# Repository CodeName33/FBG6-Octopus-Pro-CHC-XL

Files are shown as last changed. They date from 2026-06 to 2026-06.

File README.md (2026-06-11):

# FlyingBear Ghost 6 modifications for Octopus-Pro and CHC-XL
## What to buy
 * Octopus Pro H723
 * TMC2240 x5
 * "Nail" Fan 40x15 24v x2
 * "Nail" Fan 40x20 24v
 * Order custom bed heater using [drawings/heater.png](drawings/heater.png) (220v 500w) (may be here, write message to seller https://aliexpress.ru/store/911266084)
 * SSR-40-DA Relay
 * CHC-XL
 * 5Aplusreprap for PRUSAI3 MK8 (https://aliexpress.ru/item/1005003334340394.html) [images/feeder.jpg](images/feeder.jpg)
 * Nema 14 36mm (36STH20-1004HG)
 * 300x300x3 acrylic glass
 * 3D Touch [images/3dtouch.jpg](images/3dtouch.jpg)
 * 120mm FAN (PC FAN)
 * LEDS (or use Built in)
 * Any Pi computer (Oprange Pi, Raspberry Pi, etc. I use Orange Pi Zero 3)

## Connection
 * X - MOTOR0
 * Y - MOTOR1
 * Z - MOTOR3
 * Extruder - MOTOR4
 * Bed Heater (220v through Relay SSR-40-DA) - HE0
 * Bead Heater Temperature Sensor - TB
 * Hotend Heater - HE1
 * Hotend Temperature Sensor - T0
 * Hotend Fan ("Nail" Fan 40x20 24v) - FAN0 (Switch VFAN to 24v)
 * Model cool fan ("Nail" Fan 40x15 24v x2) - FAN1 (Switch VFAN to 24v)
 * Chamber fan (Built in) - FAN2 (Switch VFAN to 24v)
 * LED light - FAN3 (Switch VFAN to LEDs voltage, built in LEDs are 5v)
 * Electronics fan (120mm FAN) - FAN2 (Switch VFAN to 12v)
 * 3D Touch - PROBE
 * Pi to Octopus - (RX-TX, TX-RX, 5V-5V, GND-GND)
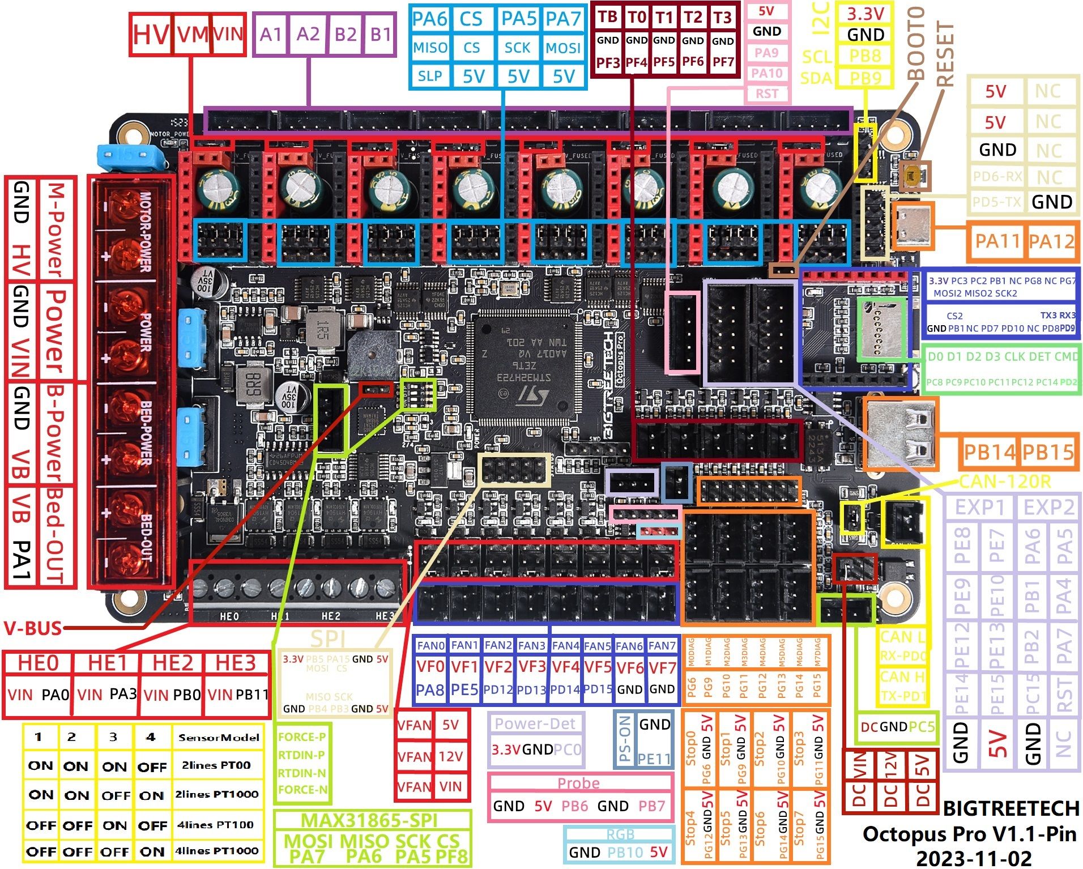
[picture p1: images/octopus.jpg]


## Folders
 * **images** - Just images
 * **drawings** - Drawings for some parts
 * **configs** - Klipper configs
 * **models** - 3d models for print (**stable** - stable models)

## Print
 1. Print "**Head VXX.stl**" from models/stable (Split it in slicer, yeah it's will be hard to print Head V1.0 bottom part). (Feeder made by Dmitry Sorkin from project Vostok)
 2. Screen not used, so panel named **screen-place.stl** can be used

(will be updated soon...)

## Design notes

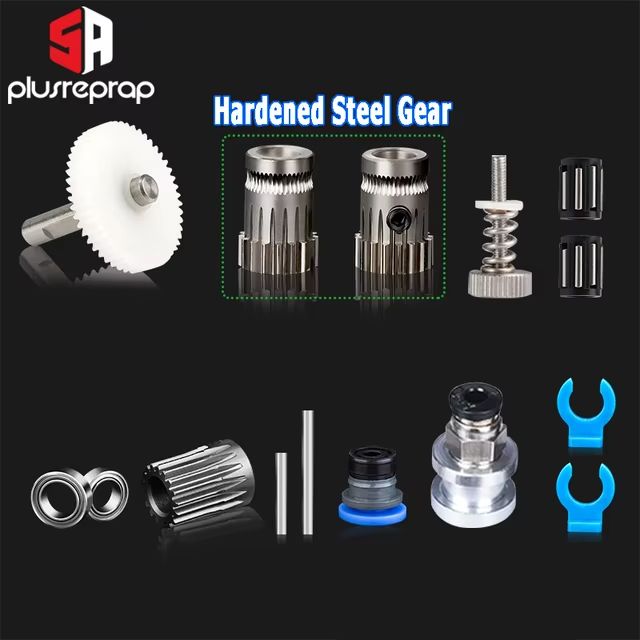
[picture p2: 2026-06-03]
images/feeder.jpg

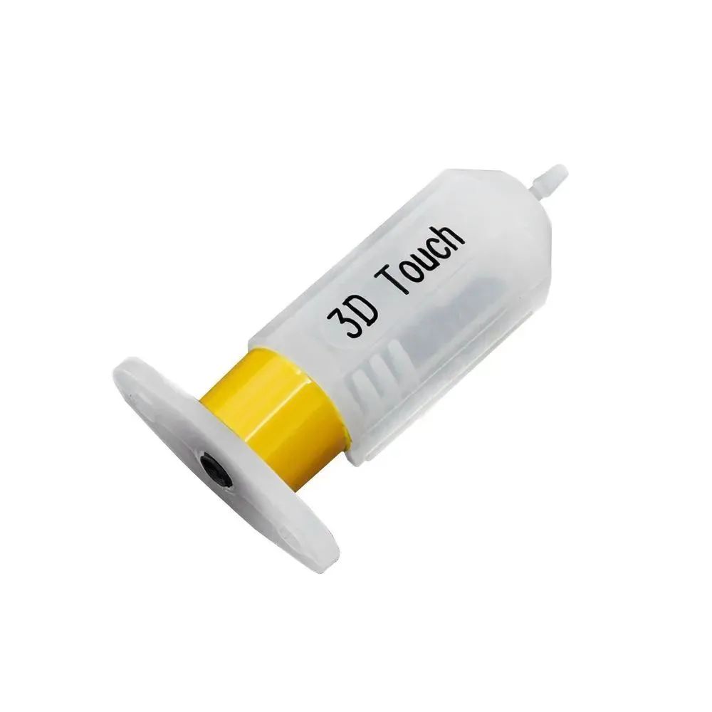
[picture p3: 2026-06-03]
images/3dtouch.jpg

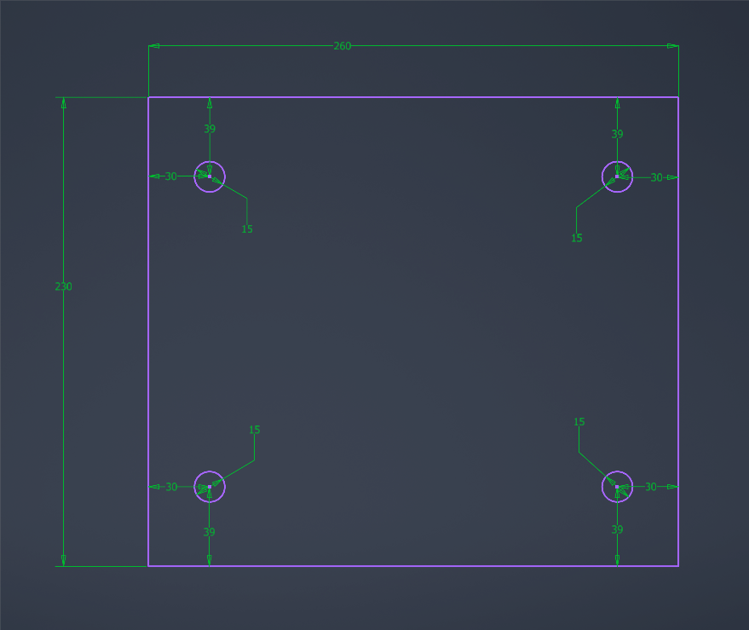
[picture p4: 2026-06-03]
drawings/heater.png

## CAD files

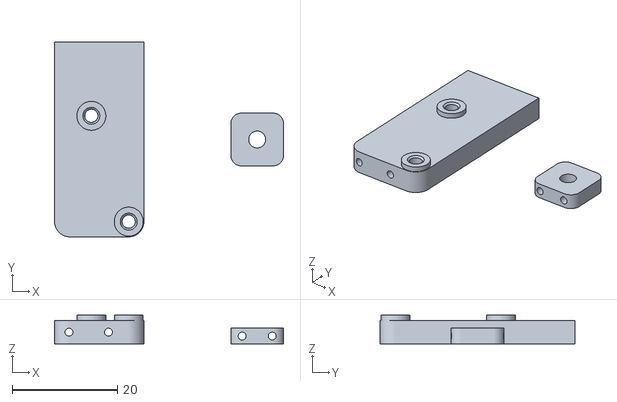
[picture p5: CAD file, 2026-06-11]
models/stable/cam-holder.stl
43.5 x 37.0 x 5.50

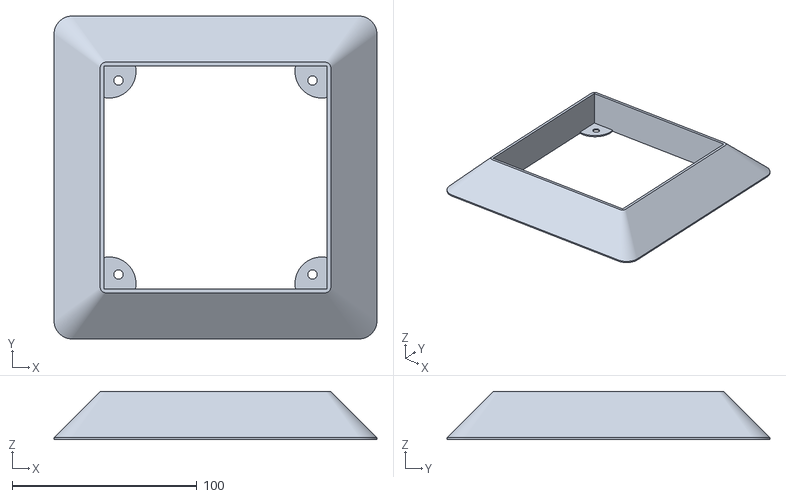
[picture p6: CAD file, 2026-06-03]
models/stable/vent-out.stl
174.8 x 174.8 x 26.0

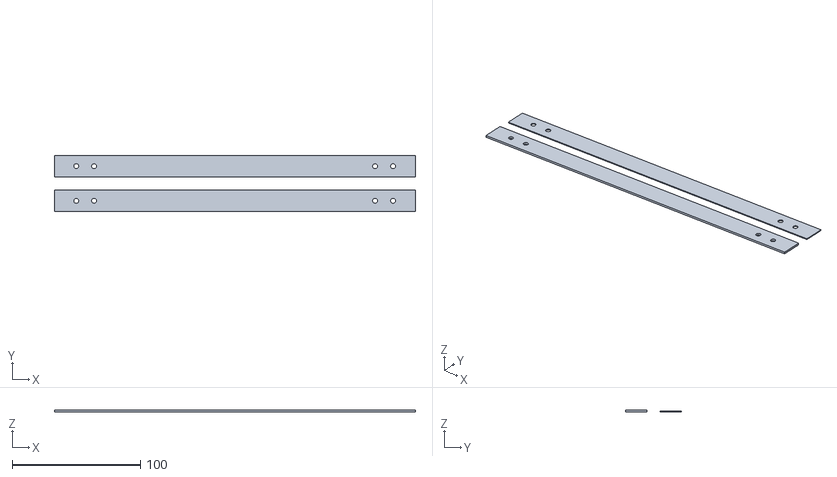
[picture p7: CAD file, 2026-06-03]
models/stable/door-fix.stl
282.0 x 44.0 x 1.50

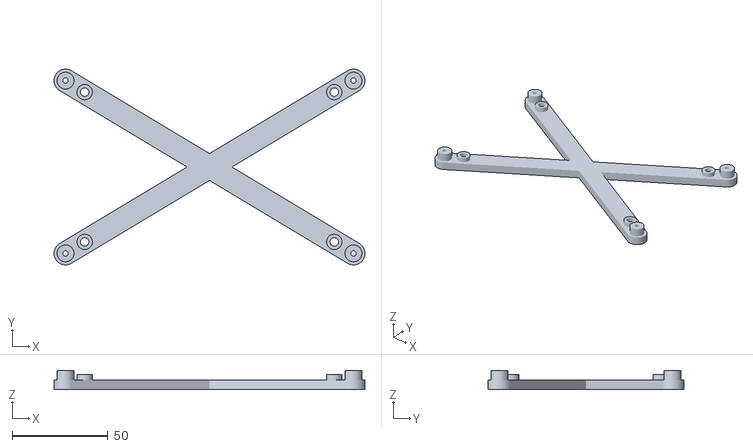
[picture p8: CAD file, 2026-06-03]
models/stable/octopus-holder.stl
162.0 x 102.0 x 10.0

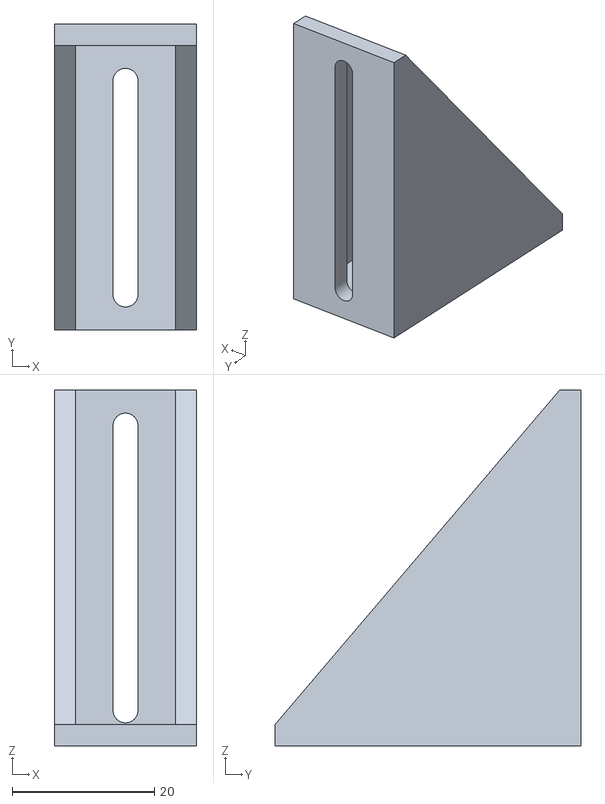
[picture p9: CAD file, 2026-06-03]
models/stable/bottom-holder.stl
20.0 x 43.0 x 50.0

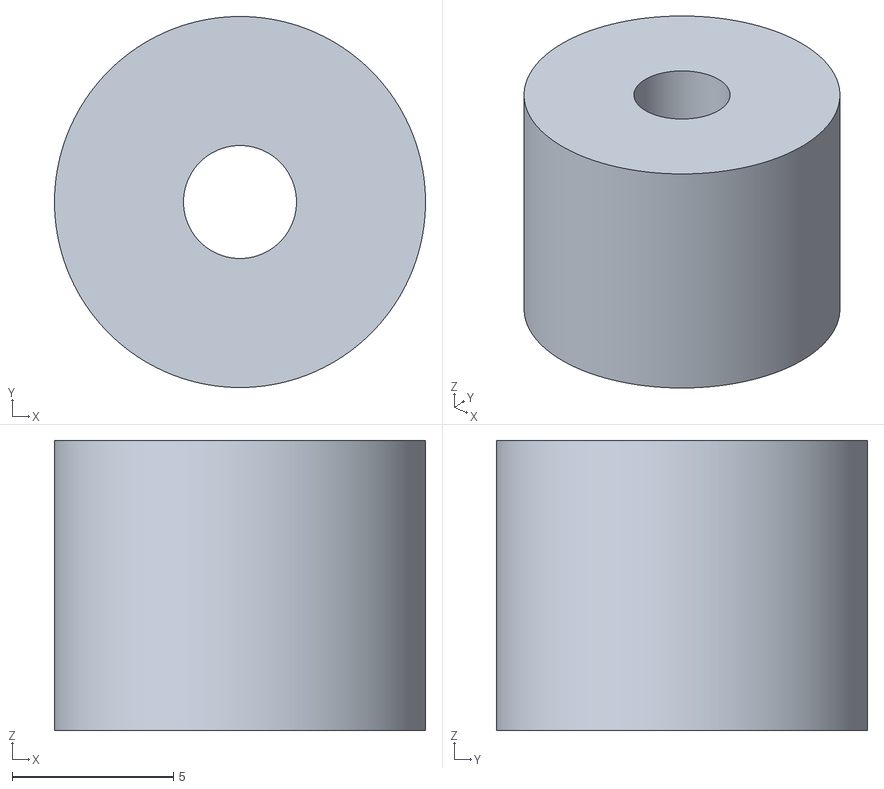
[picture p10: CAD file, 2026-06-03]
models/stable/side-holder.stl
11.5 x 11.5 x 9.00

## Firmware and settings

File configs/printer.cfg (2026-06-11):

[include printer_hardware.cfg]
[include printer_base.cfg]



[mcu]
serial: /dev/ttyS5
baud: 250000
restart_method: command 

[virtual_sdcard]
path: /home/user/printer_data/gcodes
on_error_gcode: CANCEL_PRINT

[printer]
kinematics: corexy
max_velocity: 500
max_accel: 20000
minimum_cruise_ratio: 0.5
square_corner_velocity: 10
max_z_velocity: 20
max_z_accel: 100

[stepper_x]
position_min: 0
position_endstop: 0
position_max: 255

[stepper_y]
position_min: 0
position_endstop: 0
position_max: 210

[stepper_z]
position_max: 200

[extruder]
max_temp: 320
rotation_distance: 4.5
sensor_type: PT1000
full_steps_per_rotation: 200

[heater_bed]
sensor_type: EPCOS 100K B57560G104F

[safe_z_home]
home_xy_position: 149, 132 # Центр вашего стола
speed: 400
z_hop: 6                  # Поднять сопло перед движением
z_hop_speed: 20

[bed_mesh]
mesh_min: 4.0,0.0 # Левая передняя точка, в которой будет снята карта высот стола. Указывается координата именно точки, в которой снимается высота. Положение головы при этом будет смещено на значения -x_offset и -y_offset
mesh_max: 233.0,183.0 # Правая задняя точка, в которой будет снята карта высот стола. Указывается координата именно точки, в которой снимается высота. Положение головы при этом будет смещено на значения -x_offset и -y_offset
probe_count: 9,7 # Количество точек карты высот стола вдоль осей X, Y
zero_reference_position: 127.0,105.0 # Координаты центра стола


[input_shaper]
#shaper_type_x: 3hump_ei
#shaper_freq_x: 53.38
#shaper_type_y: 3hump_ei
#shaper_freq_y: 53.38

shaper_type_x: 2hump_ei
shaper_freq_x: 54.02
shaper_type_y: 2hump_ei
shaper_freq_y: 62.02

#damping_ratio_x: 0.1
#damping_ratio_y: 0.145
#shaper_type_x: mzv
#shaper_freq_x: 30.03
#shaper_type_y: mzv
#shaper_freq_y: 33.55
#shaper_type_x: mzv
#shaper_freq_x: 60.8
#shaper_type_y: mzv
#shaper_freq_y: 57.4


#[mcu btt_s2dw]
#serial: /dev/serial/by-id/usb-Klipper_rp2040_50445061303ED21C-if00 # Замените на ваш ID

#[lis2dw]
#cs_pin: btt_s2dw:gpio9
#spi_software_sclk_pin: btt_s2dw:gpio10
#spi_software_mosi_pin: btt_s2dw:gpio11
#spi_software_miso_pin: btt_s2dw:gpio8
#axes_map: x, y, z 

#[resonance_tester]
#probe_points: 130, 100, 20 # Точка в центре стола (X, Y, Z), где будет трястись голова
#accel_chip: lis2dw


#DEBUG
[include printer_debug.cfg]

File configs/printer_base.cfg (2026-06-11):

[force_move]
enable_force_move: True

[input_shaper]

[pause_resume]

[display_status]

[respond]

[exclude_object]

[sdcard_loop]

[gcode_arcs]

[skew_correction]


[stepper_x]
microsteps: 16
rotation_distance: 40
homing_speed: 140

[stepper_y]
microsteps: 16
rotation_distance: 40
homing_speed: 140

[stepper_z]
microsteps: 16
rotation_distance: 8
second_homing_speed: 4
homing_speed: 28

position_min: -1
endstop_pin: probe:z_virtual_endstop
homing_retract_dist: 3
second_homing_speed: 3
homing_retract_dist: 5.0 

[extruder]
nozzle_diameter: 0.400
filament_diameter: 1.750
min_temp: 0
max_extrude_cross_section: 999999
max_extrude_only_distance: 200
microsteps: 16

[heater_bed]
min_temp: 0
max_temp: 120

[heater_fan hotend_fan]
heater: extruder
heater_temp: 40.0
fan_speed: 1.0

[fan]
max_power: 1.0

[controller_fan electronics_fan]
heater: extruder, heater_bed
stepper: stepper_x, stepper_y, stepper_z, extruder
fan_speed: 1.0

[bed_mesh]
speed: 400
horizontal_move_z: 3
fade_start: 1.0
fade_end: 5.0
algorithm: bicubic
mesh_pps: 0, 0
bicubic_tension: 0.1

#[screws_tilt_adjust]
#horizontal_move_z: 10
#speed: 150

# Стили: primary (синий), secondary (серый), info (голубой), warning (желтый), error (красный)


[gcode_macro _OUTPUT]
gcode:
    {% set text = params.MSG | default("") | string %}
    RESPOND MSG="<span type='WUI-OUTPUT'>{text}</span>"

[gcode_macro _CLODE_DIALOG]
gcode:
    RESPOND TYPE=command MSG="action:prompt_end"

[gcode_macro CHANGE_FILAMENT_DIALOG]
description: Сменить филамент
gcode:
    {% set unload_temp = params.UNLOAD_TEMP | default(-1) | int %}
    {% set load_temp = params.LOAD_TEMP | default(-1) | int %}
    {% set speed = params.SPEED | default(300) | int %}
    {% set length = params.LENGTH | default(60) | int %}


    _OUTPUT MSG="unload_temp = {unload_temp}..."
    {% if unload_temp == -1 %}
        RESPOND TYPE=command MSG="action:prompt_begin Выбор действия"
        RESPOND TYPE=command MSG="action:prompt_text Какой пластик выгрузить?"

        RESPOND TYPE=command MSG="action:prompt_button TPU|CHANGE_FILAMENT_DIALOG UNLOAD_TEMP=230 SPEED=150 LENGTH=60|primary"
        RESPOND TYPE=command MSG="action:prompt_button PLA|CHANGE_FILAMENT_DIALOG UNLOAD_TEMP=230 SPEED=300 LENGTH=60|primary"
        RESPOND TYPE=command MSG="action:prompt_button PETG/ABS (CF)|CHANGE_FILAMENT_DIALOG UNLOAD_TEMP=250 SPEED=300 LENGTH=60|primary"
        RESPOND TYPE=command MSG="action:prompt_button Не выгружать|CHANGE_FILAMENT_DIALOG UNLOAD_TEMP=-2|warning"
        
        RESPOND TYPE=command MSG="action:prompt_show"
    {% else %}
        {% if unload_temp != -2 %}
            RESPOND TYPE=command MSG="action:prompt_end"
            _OUTPUT MSG="Нагрев до {unload_temp}..."
            M104 S{unload_temp}
            TEMPERATURE_WAIT SENSOR=extruder MINIMUM={unload_temp}
            _OUTPUT MSG="Извлечение..."

            M83
            G1 E10 F300
            G1 E-{length} F{speed}
            _OUTPUT MSG="Извлечение завершено"
        {% endif %}

        {% if load_temp == -1 %}
            RESPOND TYPE=command MSG="action:prompt_begin Выбор действия"
            RESPOND TYPE=command MSG="action:prompt_text Какой пластик загрузить?"
    
            RESPOND TYPE=command MSG="action:prompt_button TPU|CHANGE_FILAMENT_DIALOG UNLOAD_TEMP=-2 LOAD_TEMP=230 SPEED=100 LENGTH=180|primary"
            RESPOND TYPE=command MSG="action:prompt_button PLA|CHANGE_FILAMENT_DIALOG UNLOAD_TEMP=-2 LOAD_TEMP=230 SPEED=300 LENGTH=180|primary"
            RESPOND TYPE=command MSG="action:prompt_button PETG/ABS (CF)|CHANGE_FILAMENT_DIALOG UNLOAD_TEMP=-2 LOAD_TEMP=250 SPEED=300 LENGTH=180|primary"
            RESPOND TYPE=command MSG="action:prompt_button Не Загружать|_CLODE_DIALOG|warning"
            
            RESPOND TYPE=command MSG="action:prompt_show"
        {% else %}
            RESPOND TYPE=command MSG="action:prompt_end"
            _OUTPUT MSG="Нагрев до {load_temp}..."
            M104 S{load_temp}
            TEMPERATURE_WAIT SENSOR=extruder MINIMUM={load_temp}
            _OUTPUT MSG="Загрузка..."

            M83
            G1 E10 F300
            G1 E{length} F{speed}
            _OUTPUT MSG="Загрузка завершена"
            RESPOND TYPE=command MSG="action:prompt_end"
            M104 S0
        {% endif %}
    {% endif %}
    
[gcode_macro START_PRINT]
gcode:
    {% set BED_TEMP = params.BED_TEMP|default(60)|float %}
    {% set EXTRUDER_TEMP = params.EXTRUDER_TEMP|default(200)|float %}
    {% set wait_after_bad = params.WAIT_AFTER_BED | default(0) | int %}

    # 1. Начинаем греть стол (не ждем полного нагрева для экономии времени)
    M140 S{BED_TEMP}
    
    # 2. Ждем нагрева стола
    _OUTPUT MSG="Нагрев стола  {BED_TEMP}"
    TEMPERATURE_WAIT SENSOR=heater_bed MINIMUM={BED_TEMP}

    # 3. Сброс настроек и парковка
    G90 ; Абсолютные координаты
    M83 ; Относительная экструзия
    G28 ; Home всех осей

    {% if wait_after_bad > 0 %}
        _OUTPUT MSG="Преднагрев рабочей зоны  {wait_after_bad} сек"
        G4 P{wait_after_bad * 1000}
    {% endif %}


    _OUTPUT MSG="Калибровка стола"
    # 4. (Опционально) Калибровка сетки стола
    BED_MESH_CALIBRATE

    #M109 S{EXTRUDER_TEMP}
    M104 S{EXTRUDER_TEMP}   # Установить температуру сопла
    
    # 5. Едем в точку старта для разогрева сопла (чтобы не капало на центр стола)
    G1 Z5 F3000
    G1 X5 Y5 F5000

    _OUTPUT MSG="Нагрев хотэнда"
    # 6. Ждем нагрева сопла
    TEMPERATURE_WAIT SENSOR=extruder MINIMUM={EXTRUDER_TEMP}
    
    # 7. Рисуем "линию очистки" (Prime Line)
    G1 Z0.3 F300
    G1 X100 E15 F1000 ; Первая линия
    G1 Y5.4 F5000     ; Сдвиг вбок
    G1 X10 E30 F1000  ; Вторая линия обратно
    G1 Z2 F3000       ; Приподнять сопло

    SET_SKEW XY=141.3,139.7,99.15
    _OUTPUT MSG="Печать началась"

[gcode_macro PAUSE]
rename_existing: BASE_PAUSE
gcode:
    {% set z = params.Z|default(10)|int %}                                            # Отвод по Z на 10мм
    {% set x = params.X|default(5)|int %}                                             # Парковка X в начало
    {% set y = params.Y|default(5)|int %}                                             # Парковка Y в начало
    {% set etemp = printer.extruder.target %}                                         # Запоминаем температуру
    
    SAVE_GCODE_STATE NAME=PAUSE_state
    BASE_PAUSE
    G91
    G1 E-2 F2700                                                                      # Небольшой ретракт
    G1 Z{z} F900                                                                      # Подъем Z
    G90
    G1 X{x} Y{y} F6000        

[gcode_macro RESUME]
rename_existing: BASE_RESUME
gcode:
    G91
    G1 E2 F2700                                                                       # Возвращаем пластик
    G90
    RESTORE_GCODE_STATE NAME=PAUSE_state MOVE=1
    BASE_RESUME

[gcode_macro CANCEL_PRINT]
rename_existing: BASE_CANCEL_PRINT
gcode:
    TURN_OFF_HEATERS
    CLEAR_PAUSE
    SDCARD_RESET_FILE
    END_PRINT
    BASE_CANCEL_PRINT
    _OUTPUT MSG="Печать отменена"

[gcode_macro END_PRINT]
gcode:
    # 1. Безопасный отвод сопла
    G91 ; Относительные координаты
    G1 E-3 Z5 F3000 ; Ретракт и подъем на 5мм
    G1 Z20 F600  
    
    # 2. Парковка головы и подача стола вперед (для удобства)
    G90 ; Абсолютные координаты
    G1 X0 Y0 F6000 # Замените Y280 на ваш размер стола (чтобы он выехал вперед)
    
    # 3. Выключение всего
    M106 S0 ; Выключить обдув
    M104 S0 ; Выключить хотенд
    M140 S0 ; Выключить стол
    M84 X Y E ; Выключить моторы (кроме Z, чтобы стол не упал)

    SET_SKEW CLEAR=1
    
    # Сообщение на экран
    M117 Print Finished!
    _OUTPUT MSG="Печать окончена"

[gcode_macro M106]
rename_existing: G106
gcode:
    {% if params.P is defined %}
        {% if params.P|int == 3 %}
            {% if params.S is defined %}
                SET_FAN_SPEED FAN=exhaust_fan SPEED={params.S|float / 255}
            {% else %}
                SET_FAN_SPEED FAN=exhaust_fan SPEED=1
            {% endif %}
        {% endif %}
    {% else %}
        {% if params.S is defined %}
            G106 S{params.S}
        {% else %}
            G106 S255
        {% endif %}
    {% endif %}

[gcode_macro M107]
rename_existing: G107
gcode:
    {% if params.P is defined %}
        {% if params.P|int == 3 %}
            SET_FAN_SPEED FAN=exhaust_fan SPEED=0
        {% endif %}
    {% else %}
        G107
    {% endif %}
